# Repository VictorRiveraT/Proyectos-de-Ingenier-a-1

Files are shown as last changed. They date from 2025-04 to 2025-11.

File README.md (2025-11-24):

<p align="left">
  
  <h1 align="center">SafeFry: Kit Portable para la Evaluación de Aceite Vegetal</h1>
</p>

## Descripción General
### Proyecto: Sistema de Monitoreo de Calidad de Aceite de Cocina Reutilizado mediante capacitancia y turbidez

SafeFry se centra en el desarrollo de un dispositivo portátil y de bajo costo que combina:

- La medición de la **capacitancia** del aceite de cocina reutilizado, como indicador de cambio en sus propiedades dieléctricas asociadas al deterioro.
- El sondeo de la **turbidez**, para estimar la presencia de impurezas y particulas asociadas al deterior del aceite.

La iniciativa busca facilitar la fiscalización técnica en entornos gastronómicos informales y brindar herramientas accesibles y confiables para la inspección sanitaria. De esta forma, se contribuye a la reducción de riesgos asociados al consumo de aceites degradados y a la prevención de enfermedades.

### ODS 3: Salud y Bienestar

El proyecto se enmarca dentro del ODS 3: Salud y Bienestar, particularmente en la meta 3.9: “Reducir sustancialmente el número de muertes y enfermedades por productos químicos peligrosos y contaminación del aire, agua y suelo” (ONU, 2023).

Este dispositivo busca:
- Contribuir a la seguridad alimentaria en contextos urbanos y rurales.
- Apoyar a instituciones y actores locales en la inspección sanitaria.
- Reducir el riesgo para la salud humana derivado del consumo de aceites en mal estado.

## Características Principales

- **Medición eléctrica:** Integración de un sensor capacitivo para análisis indirecto de la constante dieéectrica en el aceite, relacionado con su grado de deterioro.
- **Medición optica:** Uso de un sensor de turbidez como parametro indirecto del deterioro, con criterio de alerta en niveles altos de particulas e impurezas.
- **Interfaz intuitiva:** Visualización clara de resultados (capacitancia, turbidez, diagnóstico final).
- **Diseño portátil:** Prototipo compacto, accesible y replicable en diferentes contextos.

## Motivación y Contexto

El acceso a herramientas accesibles y confiables para evaluar la calidad de aceites de cocina reutilizados suele estar limitado por altos costos, falta de precisión o la necesidad de equipos especializados. Esto genera un riesgo para la salud pública, especialmente en entornos gastronómicos informales donde los controles sanitarios son reducidos. </p>
SafeFry nace con la intención de democratizar la evaluación de aceites, ofreciendo una alternativa portátil, de bajo costo y sencilla de implementar, que combina la medición de capacitancia con el análisis de turbidez. </p>
Este proyecto también responde a la necesidad académica de brindar a los estudiantes experiencias prácticas en el uso de tecnologías emergentes (sensado químico y sensado optico), facilitando la comprensión de conceptos de seguridad alimentaria, control de calidad y sostenibilidad en escenarios reales.

## Funcionamiento Esperado

1. La muestras de aceite se preparan y colocan en compartimentos de medición.
2. El sensor capacitivo mide la **capacitancia aparente** de la muestra, relacionada con cambios en su composición.
3. El sensor optico mide la **turbidez** del aceite para detectar su grado de deterioro.
4. El sistema procesa ambos valores y los compara con parámetros de referencia.
5. Se muestra el resultado en pantalla: Apto / No apto.

## Resultados Esperados

- Medición confiable de **capacitancia** y **turbidez** como parámetros de referencia para la evaluación de la calidad del aceite.
- Prototipo portátil y de bajo costo, diseñado para ser implementado en entornos gastronómicos informales y educativos.
- Contribución académica y social, fortaleciendo la seguridad alimentaria y promoviendo el uso de tecnologías accesibles para el control de calidad.

## Estructura del Proyecto

A continuación se detalla la organización de carpetas y archivos del repositorio:

```text
Proyectos-de-Ingenier-a-1/                        # Repositorio raíz
│
├── README.md                                     # Presentación general y documentación global
├── Fundamentos de Diseño/                        # Carpeta del curso predecesor
│
└── Proyectos de Ingeniería/                      # Carpeta principal del curso actual
    ├── Certificados/                             # Documentos de gestión y madurez TRL
    ├── Imágenes/                                 # Recursos visuales subidos
    ├── Sobre Nosotros/                           # Información de los integrantes
    ├── Talleres/                                 # Talleres y laboratorios del curso
    │
    └── Documentación/                            # Documentación técnica de ingeniería
        ├── 1.Justificación_Científica.md         # Base científica del proyecto
        ├── 2.Lista_de_Requerimientos.md          # Requisitos de portabilidad y técnicos
        ├── 3.Caja_Negra_y_Esquema_Funciones.md   # Diagramas funcionales del sistema
        ├── 4.Matriz_Morfológica.md               # Evaluación de alternativas de diseño
        ├── 5.Tabla_de_Valoración.md              # Selección de la solución final
        ├── 6.Bocetos.md                          # Dibujos preliminares del prototipo
        ├── 7.Modelo_3D.md                        # Modelado del prototipo en Onshape
        ├── 8.Esquemático.md                      # Diagramas de conexiones electrónicas
        │
        └── 9. Código/                            # Sección de Software y Firmware
            ├── README.md                         # Presentación de "SafeFry Pro" (IoT)
            │
            ├── Código_Node_Red/                  # Lógica del Dashboard IoT
            │   ├── Node-Red_Flow-Safefry.json    # Flujo completo: Dashboard y Gráficas
            │   └── README.md                     # Presentación del Flujo Node-RED
            │
            └── Código_Safefry_Aceite/            # Proyecto de Firmware (PlatformIO)
                ├── .gitignore                    # Archivos ignorados por Git
                ├── platformio.ini                # Configuración del entorno y librerías
                │
                ├── .vscode/                      # Configuración del editor VSCode
                │   └── extensions.json           # Extensiones recomendadas
                │
                ├── include/                      # Archivos de cabecera (.h) globales
                │   └── README                    # Info sobre headers
                │
                ├── lib/                          # Librerías privadas específicas
                │   └── README                    # Info sobre librerías estáticas
                │
                ├── test/                         # Pruebas unitarias del código
                │   └── README                    # Info sobre PlatformIO Test Runner
                │
                └── src/                          # Código fuente principal (C++)
                    ├── main.cpp                  # Archivo principal (Lógica de control)
                    ├── lcd_display.cpp           # Código control pantalla LCD
                    ├── lcd_display.h             # Definiciones pantalla LCD
                    ├── pulsador.cpp              # Lógica de los botones físicos
                    ├── pulsador.h                # Definiciones de botones
                    ├── sensor_capacitancia.cpp   # Lectura del sensor capacitivo (Aceite)
                    ├── sensor_capacitancia.h     # Definiciones sensor capacitivo
                    ├── sensores_turbidez.cpp     # Lectura de turbidez
                    └── sensores_turbidez.h       # Definiciones turbidez
```

## Integrantes:

| Miembro | Rol | Función Principal | Correo |
| :---: | :---: | :---: | :---: |
| **Rivera Torres Victor Daniel** | Diseño mecánico y prototipo | Diseñar y generar planos; iterar el prototipo físico | victor.rivera@upch.pe |
| **Morales Alvarado Jesús Anselmo** | Firmware y Telemetría | Programar filtrado y lógica; telemetría con envío al sitio web | jesus.morales@upch.pe |
| **Rioja Cruz Vanesa Doris** | Investigación y Requisitos | Liderar la revisión bibliográfica, definir métricas/umbrales y protocolos de calibración | vanesa.rioja@upch.pe |
| **Oscco Pizarro Gisela** | Gestión de Repositorio y Flujo de Desarrollo | Estructurar y mantener el GitHub, control de versiones de datos | gisela.oscco@upch.pe |
| **Huamani Salazar Jander** | Electrónica y Ensamble | Diseñar el esquema, cableado y ensamble electrónico | jander.huamani@upch.pe |

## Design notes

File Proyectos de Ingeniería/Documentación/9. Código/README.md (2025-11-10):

# SafeFry Pro - Sistema de Monitoreo de Calidad de Aceite

Sistema IoT profesional para monitoreo en tiempo real de la calidad del aceite de fritura mediante sensores capacitivos y de turbidez, con dashboard web interactivo y control remoto vía WiFi/UDP.

---

## Tabla de Contenidos

- [Características](#-características)
- [Requisitos](#-requisitos-del-sistema)
- [Instalación](#-instalación)
- [Documentación de Código](#-documentación-de-código)
- [Configuración](#-configuración)
- [Uso del Sistema](#-uso-del-sistema)
- [Dashboard Node-RED](#-dashboard-node-red)
- [API y Protocolos](#-api-y-protocolos)
- [Calibración de Sensores](#-calibración-de-sensores)
- [Solución de Problemas](#-solución-de-problemas)

---

## Características

### Funcionalidades Principales

-  **Monitoreo Multi-Sensor**: Medición simultánea de capacitancia y turbidez
-  **Conectividad WiFi**: Transmisión de datos en tiempo real
-  **Dashboard Web**: Interfaz gráfica profesional con Node-RED
-  **Control Remoto**: Pausa/reanuda mediciones desde cualquier dispositivo
-  **Display LCD**: Visualización local de datos y estado del sistema
-  **Toma de Decisiones**: Clasificación automática del aceite (Apto/No Apto)
-  **Histórico de Datos**: Gráficas temporales de evolución
-  **Sistema Modular**: Código organizado en clases reutilizables
-  **Calibración Flexible**: Ajuste de umbrales según tipo de aceite

### Sensores Implementados

| Sensor | Tipo | GPIO | Protocolo | Función |
|---|---|---|---|---|
| **Capacitivo** | Analógico | 25 | ADC 12-bit | Mide degradación molecular |
| **Turbidez 1** | Digital | 16/17 | UART (9600) | Detecta partículas suspendidas |
| **Turbidez 2** | Digital | 27/14 | UART (9600) | Redundancia y promediado |

### Interfaces de Usuario

1. **LCD 16x2 I2C**: Display físico local (tiempo real)
2. **Dashboard Web**: Interfaz gráfica accesible desde navegador
3. **Monitor Serial**: Logs detallados para debugging (115200 baudios)

---

## Requisitos del Sistema

### Hardware Necesario

#### Componentes Principales
- **Microcontrolador**: ESP32 DevKit (240MHz, 320KB RAM, WiFi integrado)
- **Display**: LCD 16x2 con módulo I2C (dirección 0x27)
- **Sensores**:
  - 1x Sensor capacitivo analógico (0-4095 ADC)
  - 2x Sensores de turbidez UART (protocolo propietario)
- **Entrada**: Pulsador momentáneo (pull-down)
- **Alimentación**: 5V/2A mínimo

### Software Necesario

#### En el ESP32
- **PlatformIO IDE**: v6.0 o superior (extensión VSCode)
- **Framework**: Arduino para ESP32 v3.x
- **Librerías**:
  - `ArduinoJson` v7.4.2+ (manejo de JSON)
  - `LiquidCrystal_I2C` v1.1.4+ (control LCD)
  - `WiFi` (integrado ESP32)
  - `WiFiUdp` (integrado ESP32)

#### En el Servidor (PC)
- **Node.js**: v14 LTS o superior
- **Node-RED**: v3.x
- **node-red-dashboard**: v3.6.6+

---

## Instalación

### 1. Configurar PlatformIO

```bash
# Instalar PlatformIO Core (si no está instalado)
pip install platformio

# O instalar la extensión en VSCode
# Buscar: "PlatformIO IDE" en el marketplace
```

### 2. Instalar Dependencias del ESP32

```bash
# Las dependencias se instalan automáticamente desde platformio.ini
pio pkg install

# Verificar instalación
pio pkg list
```

**Salida esperada:**
```
Library Manager
===============
ArduinoJson @ 7.4.2
LiquidCrystal_I2C @ 1.1.4
```

### 3. Configurar Node-RED

```bash
# Instalar Node-RED globalmente
npm install -g --unsafe-perm node-red

# Instalar Dashboard
npm install -g node-red-dashboard

# Iniciar Node-RED
node-red
```

### 4. Importar el Flow de Node-RED

1. Abrir navegador: `http://localhost:1880`
2. Menú ☰ → **Import** → **Clipboard**
3. Pegar el contenido de `nodered-flow.json`
4. Click **Import**
5. Click **Deploy** (botón rojo)

### 5. Configurar WiFi en el Código

Editar `src/main.cpp` (líneas 12-13):

```cpp
const char* WIFI_SSID = "TU_RED_WIFI";        // ← Cambiar
const char* WIFI_PASSWORD = "TU_CONTRASEÑA";  // ← Cambiar
```

Editar dirección IP del servidor (línea 17):

```cpp
const char* UDP_SERVER_IP = "192.168.1.XXX";  // ← IP de tu PC
```

### 6. Compilar y Subir al ESP32

```bash
# Compilar
pio run

# Subir al ESP32 (automáticamente detecta puerto)
pio run -t upload

# Abrir monitor serial
pio device monitor
```
---

## Documentación de Código

### `main.cpp` - Programa Principal

**Ubicación:** `src/main.cpp`

**Responsabilidades:**
- Orquestación de todo el sistema
- Conexión WiFi y gestión de red
- Comunicación UDP bidireccional
- Loop principal de medición
- Manejo de interrupciones del botón

**Estructura:**

```cpp
// ========== INCLUDES Y CONFIGURACIÓN ==========
#include <Arduino.h>
#include <WiFi.h>
#include <WiFiUdp.h>
#include <ArduinoJson.h>
#include "sensor_capacitancia.h"
#include "sensores_turbidez.h"
#include "lcd_display.h"
#include "pulsador.h"

// ========== CONFIGURACIÓN WiFi/UDP ==========
const char* WIFI_SSID = "...";
const char* WIFI_PASSWORD = "...";
const char* UDP_SERVER_IP = "...";
const int UDP_SERVER_PORT = 1880;
const int UDP_LOCAL_PORT = 1881;

// ========== INSTANCIAS DE OBJETOS ==========
LCDDisplay lcd(0x27, 21, 22);
SensorCapacitancia sensorCapacitivo(25);
// ... (otros sensores)

// ========== UMBRALES DE DECISIÓN ==========
const float UMBRAL_CAPACITIVO = 50.0;   // 50% degradación
const float UMBRAL_TURBIDEZ = 40.0;     // 40% turbidez

// ========== ESTRUCTURA DE DATOS ==========
struct DatosSensores {
    int capacitivoRaw;
    float capacitivoPorcentaje;
    String capacitivoEstado;
    bool capacitivoApto;
    
    int turbidez1Raw;
    int turbidez2Raw;
    float turbidezPromedio;
    String turbidezEstado;
    bool turbidezApto;
    
    bool sistemaApto;
    String decisionFinal;
};
```

**Funciones Principales:**

#### `void conectarWiFi()`
```cpp
// Conecta el ESP32 a la red WiFi configurada
// Muestra progreso en LCD y Serial
// Timeout: 30 intentos (15 segundos)
// Retorna: void (actualiza estado global)
```

#### `void enviarDatosUDP()`
```cpp
// Envía datos de sensores al servidor Node-RED
// Formato: JSON con 13 campos
// Protocolo: UDP unicast al puerto 1880
// Frecuencia: Según intervaloMedicion (default 5s)
```

#### `void procesarComandosUDP()`
```cpp
// Escucha comandos desde Node-RED en puerto 1881
// Comandos soportados:
//   - {"comando":"pausar"}
//   - {"comando":"reanudar"}
//   - {"comando":"intervalo", "valor":5000}
```

#### `void leerSensores()`
```cpp
// Lee todos los sensores y procesa datos
// 1. Lee sensor capacitivo (50 muestras promediadas)
// 2. Lee ambos sensores de turbidez (10 muestras c/u)
// 3. Calcula promedios y porcentajes
// 4. Determina estados (EXCELENTE/BUENO/REGULAR/MALO)
// 5. Toma decisión final (APTO/NO APTO)
```

**Loop Principal:**

```cpp
void loop() {
    // 1. Verificar WiFi cada 30 segundos
    verificarWiFi();
    
    // 2. Procesar comandos UDP entrantes
    procesarComandosUDP();
    
    // 3. Verificar botón físico (interrupción)
    if (boton.presionado()) {
        sistemaPausado = !sistemaPausado;
    }
    
    // 4. Ejecutar mediciones si está activo
    if (!sistemaPausado) {
        if (millis() - ultimaMedicion >= intervaloMedicion) {
            leerSensores();
            enviarDatosUDP();
            lcd.mostrarResultados(...);
            ultimaMedicion = millis();
        }
    }
}
```

---

###  `lcd_display.h/.cpp` - Control del Display LCD

**Ubicación:** `src/lcd_display.h` + `src/lcd_display.cpp`

**Descripción:**
Clase para manejar un LCD 16x2 con módulo I2C. Proporciona métodos para mostrar diferentes pantallas del sistema.

**Interfaz Pública:**

```cpp
class LCDDisplay {
public:
    LCDDisplay(uint8_t addr, int sda, int scl);
    
    // Configuración
    void begin();
    bool detectar();
    
    // Pantallas del sistema
    void mostrarInicio();
    void mostrarEsperandoBoton();
    void mostrarIniciandoSistema();
    void mostrarLeyendoSensores();
    void mostrarResultados(int capRaw, float capPorc, 
                          int turbRaw, float turbPorc, 
                          bool apto);
    void mostrarPausado();
    void mostrarError(String mensaje);
    
    // Pantallas WiFi
    void mostrarConectandoWiFi();
    void mostrarWiFiConectado(String ip);
    
    // Control básico
    void limpiar();
    void backlight(bool encender);
};
```

**Ejemplo de Uso:**

```cpp
LCDDisplay lcd(0x27, 21, 22);  // Dirección I2C, SDA, SCL

void setup() {
    lcd.begin();
    
    if (lcd.detectar()) {
        lcd.mostrarInicio();
    } else {
        lcd.mostrarError("LCD no detect");
    }
}
```

**Pantallas Implementadas:**

| Pantalla | Duración | Uso |
|---|---|-----|
| `mostrarInicio()` | 2s | Splash screen inicial |
| `mostrarConectandoWiFi()` | Variable | Durante conexión WiFi |
| `mostrarWiFiConectado(ip)` | 2s | Confirmación de conexión |
| `mostrarEsperandoBoton()` | Permanente | Espera inicio del usuario |
| `mostrarLeyendoSensores()` | 1s | Durante lectura |
| `mostrarResultados(...)` | 5s | Datos + decisión (alternante) |
| `mostrarPausado()` | Permanente | Sistema en pausa |

---

### `sensor_capacitancia.h/.cpp` - Sensor Capacitivo

**Ubicación:** `src/sensor_capacitancia.h` + `src/sensor_capacitancia.cpp`

**Descripción:**
Clase para leer y procesar un sensor capacitivo analógico que mide la degradación del aceite basándose en cambios en su constante dieléctrica.

**Principio de Funcionamiento:**
```
Aceite Fresco    →  Alta capacitancia (≈3130)  →  0% degradación
Aceite Degradado →  Baja capacitancia (≈3140)  →  100% degradación
```

**Interfaz Pública:**

```cpp
class SensorCapacitancia {
public:
    SensorCapacitancia(int pinSensor);
    
    // Configuración
    void begin();
    void calibrar(int aire, int agua, int limpio, int sucio);
    void setNumLecturas(int num);
    
    // Lectura
    int leerRaw();              // Valor ADC (0-4095)
    float leerPorcentaje();     // Degradación (0-100%)
    
    // Utilidades
    String obtenerEstado();
    String obtenerEstadoDetallado(float porcentaje);
};
```

**Calibración:**

```cpp
sensorCapacitivo.calibrar(
    3430,  // Valor en aire (máximo)
    290,   // Valor en agua (mínimo)
    3130,  // Aceite limpio
    3140   // Aceite degradado
);
```

**Algoritmo de Lectura:**

```cpp
int SensorCapacitancia::leerRaw() {
    long suma = 0;
    for (int i = 0; i < numLecturas; i++) {  // Default: 50
        suma += analogRead(pin);
        delay(10);  // 10ms entre muestras
    }
    return suma / numLecturas;  // Promedio
}

float SensorCapacitancia::leerPorcentaje() {
    int raw = leerRaw();
    // Mapeo inverso: limpio(3130)→0%, sucio(3140)→100%
    return map(raw, valorSucio, valorLimpio, 0, 100);
}
```

**Estados de Clasificación:**

| Porcentaje | Estado | Descripción |
|---|---|---|
| 0-24% | EXCELENTE | Aceite en condiciones óptimas |
| 25-49% | BUENO | Aceite apto, sin degradación significativa |
| 50-74% | REGULAR | Aceite con degradación moderada |
| 75-100% | MALO | Aceite altamente degradado, cambiar |

---

### `sensores_turbidez.h/.cpp` - Sensores de Turbidez

**Ubicación:** `src/sensores_turbidez.h` + `src/sensores_turbidez.cpp`

**Descripción:**
Clase para comunicarse con sensores de turbidez que usan protocolo UART propietario. Mide la cantidad de partículas suspendidas en el aceite.

**Protocolo de Comunicación:**

```
Comando de lectura (5 bytes):
[0x18] [0x05] [0x00] [0x01] [0x0D]
  ↓      ↓      ↓      ↓      ↓
 Start  Cmd   Addr  Length  End

Respuesta del sensor (5 bytes):
[0x??] [0x??] [0x??] [VALUE] [0x??]
                       ↑
                 Dato de turbidez (0-255)
```

**Interfaz Pública:**

```cpp
class SensorTurbidez {
public:
    SensorTurbidez(HardwareSerial* port, int rx, int tx);
    
    // Configuración
    void begin();
    void calibrar(int limpio, int sucio);
    void setNumLecturas(int num);
    
    // Lectura
    int leerRaw();                      // Valor (0-255)
    float leerPorcentajeSuciedad();    // Suciedad (0-100%)
    
    // Utilidades
    String obtenerEstado();
    String obtenerEstadoDetallado(float porcentaje);
    bool disponible();
};
```

**Calibración:**

```cpp
sensorTurbidez1.calibrar(
    243,  // Aceite limpio (valor alto)
    205   // Aceite sucio (valor bajo)
);
```

**Algoritmo de Lectura:**

```cpp
int SensorTurbidez::leerRaw() {
    long suma = 0;
    int lecturasValidas = 0;
    
    for (int i = 0; i < 10; i++) {  // 10 intentos
        // 1. Limpiar buffer
        while (serial->available()) serial->read();
        
        // 2. Enviar comando
        serial->write(comandoLectura, 5);
        
        // 3. Esperar respuesta (timeout 500ms)
        unsigned long inicio = millis();
        while (serial->available() < 5 && 
               (millis() - inicio) < 500) {
            delay(10);
        }
        
        // 4. Leer respuesta
        if (serial->available() >= 5) {
            for (int j = 0; j < 5; j++) {
                buffer[j] = serial->read();
            }
            suma += buffer[3];  // Byte de datos
            lecturasValidas++;
        }
        
        delay(100);  // Pausa entre lecturas
    }
    
    return (lecturasValidas > 0) ? 
           suma / lecturasValidas : -1;  // -1 = error
}
```

**Promediado de Sensores:**

```cpp
// En main.cpp
float turbidez1 = sensorTurbidez1.leerPorcentajeSuciedad();
float turbidez2 = sensorTurbidez2.leerPorcentajeSuciedad();

if (turbidez1 >= 0 && turbidez2 >= 0) {
    turbidezPromedio = (turbidez1 + turbidez2) / 2.0;  // Promedio
} else if (turbidez1 >= 0) {
    turbidezPromedio = turbidez1;  // Solo sensor 1
} else if (turbidez2 >= 0) {
    turbidezPromedio = turbidez2;  // Solo sensor 2
} else {
    turbidezPromedio = -1;  // Error total
}
```

---

### `pulsador.h/.cpp` - Control del Botón

**Ubicación:** `src/pulsador.h` + `src/pulsador.cpp`

**Descripción:**
Clase para manejar un pulsador con interrupciones y antirrebote por software.

**Interfaz Pública:**

```cpp
class Pulsador {
public:
    Pulsador(int pinBoton, unsigned long debounce = 200);
    void begin();
    bool presionado();  // Retorna true si fue presionado
    
private:
    static void IRAM_ATTR manejarInterrupcion();
    static volatile bool flagGlobal;
    static volatile unsigned long ultimoTiempoGlobal;
};
```

**Implementación del Antirrebote:**

```cpp
void IRAM_ATTR Pulsador::manejarInterrupcion() {
    unsigned long tiempoActual = millis();
    
    // Ignorar rebotes en 200ms
    if (tiempoActual - ultimoTiempoGlobal > 200) {
        flagGlobal = true;
        ultimoTiempoGlobal = tiempoActual;
    }
}

bool Pulsador::presionado() {
    if (flagGlobal) {
        flagGlobal = false;  // Reset flag
        return true;
    }
    return false;
}
```

**Configuración de Hardware:**

```
GPIO 26 ────┬──── Pulsador ──── VCC
            │
           ═╧═  10kΩ Pull-down
            │
           GND
```

---

## Configuración

### Configuración WiFi

Editar en `src/main.cpp`:

```cpp
// ========== CONFIGURACIÓN WiFi ==========
const char* WIFI_SSID = "TU_RED_WIFI";
const char* WIFI_PASSWORD = "TU_CONTRASEÑA";
```

**Requisitos:**
-  Red WiFi 2.4 GHz (ESP32 no soporta 5 GHz)
-  DHCP habilitado (asignación automática de IP)
-  Sin firewall que bloquee UDP

### Configuración UDP

```cpp
// ========== CONFIGURACIÓN UDP ==========
const char* UDP_SERVER_IP = "192.168.1.100";  // IP de tu PC
const int UDP_SERVER_PORT = 1880;             // Puerto entrada
const int UDP_LOCAL_PORT = 1881;              // Puerto escucha
```

**Verificar IP de tu PC:**

Windows:
```cmd
ipconfig
```

Linux/Mac:
```bash
ifconfig
```

### Configuración de Umbrales

```cpp
// ========== UMBRALES DE DECISIÓN ==========
const float UMBRAL_CAPACITIVO = 50.0;  // % degradación
const float UMBRAL_TURBIDEZ = 40.0;    // % turbidez
```

**Lógica de Decisión:**
```cpp
bool aptoCap = (capacitancia < UMBRAL_CAPACITIVO);
bool aptoTurb = (turbidez < UMBRAL_TURBIDEZ);
bool sistemaApto = aptoCap && aptoTurb;  // Ambos deben ser aptos
```

### Configuración de Sensores

#### Sensor Capacitivo
```cpp
sensorCapacitivo.begin();
sensorCapacitivo.calibrar(3430, 290, 3130, 3140);
sensorCapacitivo.setNumLecturas(50);  // 50 muestras
```

#### Sensores de Turbidez
```cpp
sensorTurbidez1.begin();
sensorTurbidez1.calibrar(243, 205);  // Limpio, Sucio

sensorTurbidez2.begin();
sensorTurbidez2.calibrar(243, 205);
```

---

## Uso del Sistema

### Inicio del Sistema

1. **Conexión de Hardware**
   - Conectar todos los sensores según diagrama
   - Conectar LCD I2C
   - Conectar pulsador
   - Alimentar ESP32 (5V/2A)

2. **Arranque Automático**
   ```
   [LCD] SAFEFRY v1.1
         Monitor Aceite
   
   [LCD] Conectando
         WiFi...
   
   [LCD] WiFi OK!
         192.168.1.123
   
   [LCD] Presiona boton
         para iniciar
   ```

3. **Iniciar Mediciones**
   - Presionar botón físico (GPIO 26)
   - O desde dashboard web: click **▶️ REANUDAR**

### Operación Normal

**Ciclo de Medición (cada 5 segundos):**

```
1. [LCD] Leyendo sensores...         (1 segundo)
2. [Serial] Log detallado de datos   (contínuo)
3. [LCD] C:3135  T:223               (3 segundos)
        45%    35%    OK
4. [LCD] DECISION FINAL:             (2 segundos)
        *** APTO ***
5. [UDP] Envío de JSON al servidor
6. [Dashboard] Actualización gráfica
```

### Control Remoto

Desde el dashboard web (`http://IP_PC:1880/ui`):

| Acción | Efecto | Feedback |
|---|---|---|
| **⏸️ PAUSAR** | Detiene mediciones | LCD: "SISTEMA PAUSADO" |
| **▶️ REANUDAR** | Inicia mediciones | LCD: "Iniciando... Sistema" |
| ** Slider** | Cambia intervalo (1-30s) | Serial: "Intervalo cambiado a: Xs" |

### Lectura del LCD

**Pantalla 1 - Valores RAW (3s):**
```
┌────────────────┐
│C:3135    T:223 │  ← Valores RAW de sensores
│45%       35% OK│  ← Porcentajes + Estado
└────────────────┘
```

**Pantalla 2 - Decisión (2s):**
```
┌────────────────┐
│DECISION FINAL: │
│  *** APTO ***  │
└────────────────┘
```

### Monitor Serial

**Ejemplo de salida:**

```
╔════════════════════════════════════════════╗
║         LEYENDO SENSORES SAFEFRY          ║
╚════════════════════════════════════════════╝

 SENSOR CAPACITIVO:
  RAW: 3135 | Degradación: 45.5% | Estado: BUENO | ✅ APTO

 SENSORES DE TURBIDEZ:
  Sensor 1: 225 (35.2%)
  Sensor 2: 220 (34.8%)
  Promedio: 35.0% NTU | Estado: BUENO | ✅ APTO

╔════════════════════════════════════════════╗
║        DECISIÓN FINAL: ✅ APTO            ║
╚════════════════════════════════════════════╝

 Datos enviados por UDP:
{"timestamp":12345,"capacitancia_raw":3135,...}
```

---

## Dashboard Node-RED

### Acceso al Dashboard

```
Local:     http://localhost:1880/ui
Red local: http://192.168.1.100:1880/ui
Móvil:     http://IP_PC:1880/ui
```

### Componentes del Dashboard

#### 1. Indicadores Principales

**Gauges Tipo Donut:**
- **Turbidez**: 0-100% (Verde: 0-40, Amarillo: 40-70, Rojo: 70-100)
- **Capacitancia**: 0-100% (Verde: 0-50, Amarillo: 50-75, Rojo: 75-100)

**Características:**
- Actualización en tiempo real
- Animación suave
- Colores dinámicos según valor

#### 2. Estado del Sistema

**Banner Principal:**
```css
┌────────────────────────────────────┐
│                                    │
│         ✅ APTO                    │  ← Gradiente morado
│                                    │     Fuente grande, sombras
└────────────────────────────────────┘
```

**Indicador de Decisión:**
- ✅ SISTEMA APTO (verde)
- ❌ NO APTO (rojo)

#### 3. Histórico de Mediciones

**Gráfica de Líneas:**
- Eje X: Tiempo (HH:mm:ss)
- Eje Y: Porcentaje (0-100%)
- Línea azul: Turbidez
- Línea naranja: Capacitancia
- Histórico: Últimos 5 minutos
- Interpolación: Lineal
- Zoom: Interactivo

#### 4. Valores RAW

**Displays grandes:**
```
┌─────────────────────┐  ┌─────────────────────┐
│    Turbidez RAW     │  │    Capacitancia RAW │
│                     │  │                     │
│       223           │  │       3135          │
│   (fuente 36px)     │  │   (fuente 36px)     │
└─────────────────────┘  └─────────────────────┘
```

#### 5. Estados Detallados

**Texto descriptivo:**
-  Capacitancia: BUENO (45.5%)
-  Turbidez: EXCELENTE (35.0%)

**Indicadores de estado:**
- Cap: ✅ APTO / ❌ NO APTO
- Turb: ✅ APTO / ❌ NO APTO
- Sistema: ▶️ ACTIVO / ⏸️ PAUSADO

#### 6. Resumen Completo

**Tabla HTML estilizada:**

| Parámetro | Valor | Estado |
|---|---|---|
| Capacitancia RAW | 3135 | ✅ APTO |
| Capacitancia % | 45.5% | BUENO |
| Turbidez Sensor 1 RAW | 225 | - |
| Turbidez Sensor 2 RAW | 220 | - |
| Turbidez Promedio RAW | 223 | ✅ APTO |
| Turbidez % | 35.0% | EXCELENTE |
| **DECISIÓN FINAL** | **✅ APTO** | **✅ SISTEMA APTO** |
| Última actualización | 09/11/2025 15:30:45 | - |

**Características:**
- Hover effects
- Badges coloridos
- Responsive design
- Exportable

#### 7. Control Remoto

**Botones:**
- ⏸️ **PAUSAR**: Botón rojo, detiene mediciones
- ▶️ **REANUDAR**: Botón verde, inicia mediciones

**Slider de Intervalo:**
- Rango: 1-30 segundos
- Paso: 1 segundo
- Feedback inmediato
- Indicador de valor actual

### Ejemplo Visual del Dashboard

```
╔═══════════════════════════════════════════════════════════╗
║                SafeFry Dashboard Pro                    ║
╠═══════════════════════════════════════════════════════════╣
║    INDICADORES PRINCIPALES                              ║
║  ┌──────────┐  ┌──────────┐                             ║
║  │    35%  │  │    45%  │  (Gauges donut)             ║
║  └──────────┘  └──────────┘                             ║
║                                                          ║
║  🚦 ESTADO DEL SISTEMA                                   ║
║  ┌────────────────────────────────────────┐             ║
║  │          ✅ APTO                       │ (Banner)    ║
║  └────────────────────────────────────────┘             ║
║  ✅ SISTEMA APTO                           (Decisión)    ║
║                                                          ║
║  📈 HISTÓRICO                                            ║
║  ┌────────────────────────────────────────┐             ║
║  │      ╱╲    ╱╲                          │             ║
║  │    ╱    ╲╱    ╲                        │ (Gráfica)   ║
║  │  ╱                                     │             ║
║  └────────────────────────────────────────┘             ║
║                                                          ║
║  🔢 VALORES RAW                                          ║
║  ┌──────────┐  ┌──────────┐                             ║
║  │   223    │  │   3135   │                             ║
║  └──────────┘  └──────────┘                             ║
║                                                          ║
║    ESTADOS: ✅ Cap OK  ✅ Turb OK  ▶️ Activo            ║
║                                                          ║
║    TABLA COMPLETA                                       ║
║  [Tabla con todos los datos detallados]                 ║
║                                                          ║
║    CONTROL REMOTO                                      ║
║  [⏸️ PAUSAR] [▶️ REANUDAR] [━━━━◉━━━ 5s]               ║
╚═══════════════════════════════════════════════════════════╝
```

---

## 📡 API y Protocolos

### Protocolo UDP

#### Formato de Datos (ESP32 → Node-RED)

**Puerto:** 1880  
**Protocolo:** UDP  
**Formato:** JSON  

**Estructura del JSON:**

```json
{
  "timestamp": 12345,
  "capacitancia_raw": 3135,
  "capacitancia": 45.5,
  "capacitancia_estado": "BUENO",
  "capacitancia_apto": true,
  "turbidez1_raw": 225,
  "turbidez2_raw": 220,
  "turbidez_promedio_raw": 223,
  "turbidez": 35.0,
  "turbidez_estado": "EXCELENTE",
  "turbidez_apto": true,
  "sistema_apto": true,
  "estado": "✅ APTO",
  "pausado": false
}
```

**Campos:**

| Campo | Tipo | Rango | Descripción |
|---|---|---|---|
| `timestamp` | int | 0-∞ | Milisegundos desde inicio |
| `capacitancia_raw` | int | 0-4095 | Valor ADC 12-bit |
| `capacitancia` | float | 0-100 | % de degradación |
| `capacitancia_estado` | string | - | EXCELENTE/BUENO/REGULAR/MALO |
| `capacitancia_apto` | bool | - | true/false |
| `turbidez1_raw` | int | 0-255 | Sensor 1 RAW |
| `turbidez2_raw` | int | 0-255 | Sensor 2 RAW |
| `turbidez_promedio_raw` | int | 0-255 | Promedio RAW |
| `turbidez` | float | 0-100 | % de suciedad |
| `turbidez_estado` | string | - | EXCELENTE/BUENO/REGULAR/MALO/MUY_MALO |
| `turbidez_apto` | bool | - | true/false |
| `sistema_apto` | bool | - | true/false (AND de ambos) |
| `estado` | string | - | "✅ APTO" / "❌ NO APTO" |
| `pausado` | bool | - | Estado del sistema |

#### Comandos (Node-RED → ESP32)

**Puerto:** 1881  
**Protocolo:** UDP Broadcast  
**Formato:** JSON  

**1. Pausar Sistema:**
```json
{
  "comando": "pausar"
}
```

**2. Reanudar Sistema:**
```json
{
  "comando": "reanudar"
}
```

**3. Cambiar Intervalo:**
```json
{
  "comando": "intervalo",
  "valor": 5000
}
```
**Rango válido:** 1000-60000 ms

### Diagrama de Secuencia

```
ESP32                    Node-RED
  │                         │
  ├─────── WiFi Connect ────│
  │◄──────── DHCP IP ───────┤
  │                         │
  ├── UDP(1880): JSON ──────►│ [Procesar datos]
  │                         │ [Actualizar dashboard]
  │                         │ [Usuario: Click PAUSAR]
  │◄─ UDP(1881): {"pausar"} ┤
  │                         │
  [Sistema pausado]         │
  │                         │
  │◄─ UDP(1881): {"reanudar"} ┤
  │                         │
  ├── UDP(1880): JSON ──────►│
  │    (ciclo continúa)      │
```

---

## Calibración de Sensores

### Sensor Capacitivo

#### Procedimiento de Calibración

**1. Calibración en Aire (máximo):**
```cpp
// Sensor al aire libre, sin contacto
int valorAire = sensorCapacitivo.leerRaw();
// Valor esperado: ~3430
```

**2. Calibración en Agua (mínimo):**
```cpp
// Sensor sumergido en agua destilada
int valorAgua = sensorCapacitivo.leerRaw();
// Valor esperado: ~290
```

**3. Calibración con Aceite Limpio:**
```cpp
// Sensor en aceite fresco sin usar
int valorLimpio = sensorCapacitivo.leerRaw();
// Valor esperado: ~3130
```

**4. Calibración con Aceite Degradado:**
```cpp
// Sensor en aceite muy usado/oscuro
int valorSucio = sensorCapacitivo.leerRaw();
// Valor esperado: ~3140
```

**5. Aplicar Calibración:**
```cpp
sensorCapacitivo.calibrar(
    valorAire,    // 3430
    valorAgua,    // 290
    valorLimpio,  // 3130
    valorSucio    // 3140
);
```

#### Troubleshooting

| Problema | Causa | Solución |
|---|---|---|
| Lecturas erráticas | Ruido eléctrico | Agregar capacitor 100nF |
| Valores fuera de rango | Mala conexión | Verificar soldaduras |
| No detecta cambios | Sensor dañado | Reemplazar sensor |

### Sensores de Turbidez

#### Procedimiento de Calibración

**1. Calibración con Aceite Limpio:**
```cpp
// Sumergir sensor en aceite fresco
// Realizar múltiples lecturas
int sum = 0;
for (int i = 0; i < 10; i++) {
    sum += sensorTurbidez1.leerRaw();
    delay(1000);
}
int valorLimpio = sum / 10;
// Valor esperado: ~243
```

**2. Calibración con Aceite Sucio:**
```cpp
// Aceite muy usado o con partículas añadidas
int valorSucio = /* promedio de 10 lecturas */;
// Valor esperado: ~205
```

**3. Aplicar Calibración:**
```cpp
sensorTurbidez1.calibrar(valorLimpio, valorSucio);
sensorTurbidez2.calibrar(valorLimpio, valorSucio);
```

#### Mantenimiento

- **Limpieza:** Limpiar lentes cada semana con alcohol isopropílico
- **Verificación:** Calibrar cada mes o ante lecturas anómalas
- **Almacenamiento:** Guardar en lugar seco cuando no se use

---

## Solución de Problemas

### WiFi

#### ❌ ESP32 no se conecta a WiFi

**Síntomas:**
- LCD muestra "Conectando WiFi..." indefinidamente
- Serial: "❌ Error: No se pudo conectar a WiFi"

**Soluciones:**

1. **Verificar credenciales:**
   ```cpp
   const char* WIFI_SSID = "NOMBRE_EXACTO";
   const char* WIFI_PASSWORD = "contraseña_exacta";
   ```

2. **Verificar frecuencia de red:**
   - ESP32 solo soporta 2.4 GHz
   - Desactivar temporalmente banda 5 GHz del router

3. **Verificar rango de señal:**
   ```cpp
   Serial.print("Señal: ");
   Serial.print(WiFi.RSSI());
   Serial.println(" dBm");
   // Ideal: > -50 dBm
   // Bueno: -50 a -70 dBm
   // Malo: < -70 dBm
   ```

4. **Reset WiFi manual:**
   ```cpp
   WiFi.disconnect(true);
   delay(1000);
   WiFi.begin(WIFI_SSID, WIFI_PASSWORD);
   ```

#### Conecta pero pierde conexión

**Solución:** La función `verificarWiFi()` ya maneja reconexión automática cada 30s.

### UDP

#### Dashboard no recibe datos

**Checklist:**

1. ✅ **Firewall de Windows:**
   ```cmd
   # Verificar reglas
   netsh advfirewall firewall show rule name=all | findstr "1880"
   
   # Si no existe, crear regla
   netsh advfirewall firewall add rule name="Node-RED UDP 1880" dir=in action=allow protocol=UDP localport=1880
   ```

2. ✅ **IP correcta:**
   ```cpp
   // En main.cpp, verificar que coincide con tu PC
   const char* UDP_SERVER_IP = "192.168.1.100";
   ```
   
   ```cmd
   # Windows: obtener tu IP
   ipconfig | findstr IPv4
   ```

3. ✅ **Node-RED escuchando:**
   ```cmd
   netstat -an | findstr "1880"
   # Debe mostrar: UDP 0.0.0.0:1880
   ```

4. ✅ **Debug en Serial:**
   ```
   📤 Datos enviados por UDP:
   {"timestamp":12345,...}
   ```

5. ✅ **Debug en Node-RED:**
   - Abrir pestaña "Debug"
   - Verificar nodo "🔍 Debug Datos"
   - Debe aparecer el JSON recibido

#### Comandos no llegan al ESP32

**Solución:**

1. Verificar que ESP32 escucha en 1881:
   ```cpp
   Serial.print("🔌 UDP escuchando en puerto: ");
   Serial.println(UDP_LOCAL_PORT);  // Debe ser 1881
   ```

2. En Node-RED, nodo "📤 UDP Salida":
   - Campo "Address": **dejar en BLANCO**
   - Multicast: **broadcast**

3. Test manual:
   ```python
   # Python script para test
   import socket
   import json
   
   sock = socket.socket(socket.AF_INET, socket.SOCK_DGRAM)
   sock.setsockopt(socket.SOL_SOCKET, socket.SO_BROADCAST, 1)
   
   mensaje = json.dumps({"comando": "pausar"})
   sock.sendto(mensaje.encode(), ('<broadcast>', 1881))
   ```

### Sensores

#### Sensor capacitivo da valores constantes

**Diagnóstico:**
```cpp
// En setup(), agregar:
Serial.print("Test ADC GPIO 25: ");
Serial.println(analogRead(25));
// Debe variar entre 0-4095
```

**Causas:**
- Pin no configurado como INPUT
- Sensor desconectado
- Sensor en corto

**Solución:**
```cpp
pinMode(25, INPUT);
analogReadResolution(12);  // 12 bits
```

#### Sensores de turbidez no responden

**Diagnóstico:**
```cpp
int raw1 = sensorTurbidez1.leerRaw();
Serial.println(raw1);  // -1 = error, 0-255 = OK
```

**Causas comunes:**

1. **Baudrate incorrecto:**
   ```cpp
   serial->begin(9600, SERIAL_8N1, pinRx, pinTx);
   ```

2. **Pines RX/TX invertidos:**
   ```
   ESP32 RX → Sensor TX
   ESP32 TX → Sensor RX
   ```

3. **Alimentación insuficiente:**
   - Sensores requieren 5V estable
   - Verificar con multímetro

4. **Comando incorrecto:**
   ```cpp
   unsigned char comandoLectura[5] = {0x18, 0x05, 0x00, 0x01, 0x0D};
   ```

### LCD

#### LCD no detectado

**Diagnóstico:**
```cpp
if (!lcd.detectar()) {
    Serial.println("❌ LCD no detectado");
    // Probar direcciones alternativas
    for (uint8_t addr = 0x20; addr <= 0x27; addr++) {
        Wire.beginTransmission(addr);
        if (Wire.endTransmission() == 0) {
            Serial.print("✅ Dispositivo I2C en: 0x");
            Serial.println(addr, HEX);
        }
    }
}
```

**Direcciones comunes:**
- 0x27 (default)
- 0x3F
- 0x20

**Solución:**
```cpp
LCDDisplay lcd(0x3F, 21, 22);  // Cambiar dirección
```

#### LCD muestra caracteres raros

**Causas:**
- Contraste mal ajustado (potenciómetro en módulo I2C)
- Inicialización fallida

**Solución:**
```cpp
lcd.begin();
delay(100);
lcd.begin();  // Doble inicialización
```

---

</div>

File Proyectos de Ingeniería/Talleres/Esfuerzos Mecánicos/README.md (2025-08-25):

# Informe de Taller – Simulación de Fallas Mecánicas en SimScale

## 1. Título
**Análisis de deformaciones y esfuerzos mecánicos mediante simulación en SimScale**

---

## 2. Objetivos
- Comprender el uso de la plataforma **SimScale** para realizar análisis de esfuerzos y deformaciones en sólidos.  
- Simular distintos tipos de cargas mecánicas (tracción, compresión, corte, etc) aplicadas a un modelo 3D importado desde Onshape.  
- Visualizar gráficamente la deformación y los esfuerzos internos mediante colorimetría y escalas de Von Mises.  
- Interpretar los resultados obtenidos y relacionarlos con los conceptos teóricos de resistencia de materiales.

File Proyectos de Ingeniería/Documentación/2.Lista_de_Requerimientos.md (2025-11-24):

<p align="left">
  
  <h1 align="center">Lista de Requerimientos</h1>
</p>

Proyecto: **Sistema de Monitoreo de Calidad de Aceite de Cocina Reutilizado mediante capacitancia y turbidez**  
Institución: Universidad Peruana Cayetano Heredia  
Fecha Primera Revisión: 18/08/2025  

| Fecha | Tipo | Exigencia | Descripción | Responsable |
|---|---|---|---|---|
| 09/09/25 | E | Función principal | El dispositivo debe medir la calidad del aceite vegetal usado a través de **capacitancia** (relacionado con cambios en la constante dieléctrica del aceite debido a la degradación de sus componentes) y **turbidez** (indicador indirecto de la presencia de impurezas y particulas en suspensión). Ambos parámetros son aceptados en la literatura como indicadores de deterioro. | J.M, J.H, Vanesa R, Victor R, G.O |
| 09/09/25 | E | Funcion secundaria | El dispositivo debe mostrar el nivel de calidad de aceite( Apto/ No apto ) mediante un indicador visual y/o pantalla LCD de forma clara y legible. | Vanesa R, Victor R |
| 09/09/25 | E | Medición de parámetros | **Capacitancia aparente:** rango 0–1000 pF(ajustable segun calibración), resolución ±0.1 pF; alerta si la variación excede valores de referencia establecidos en pruebas experimentales(indicando deterioro). <br> **Turbidez en NTU:** (0-3000) con umbral critico > 500 NTU empleando dispersión de luz para detectar particulas quemadas del aceite. | J.M, J.H, G.O |
| 18/08/25 | E | Geometría y portabilidad | Prototipo compacto y liviano (<1.5 kg). Dimensiones: alto: 23 cm, largo: 21 cm, ancho 11.5 cm diseñado para transporte en mochila y uso en campo (ISO 7250). | Victor R |
| 18/08/25 | D | Energía y autonomía | Autonomía mínima de 8 horas con baterías recargables de bajo costo; salida en corriente continua de 3–5 V. | G.O |
| 09/09/25 | E | Software y control | El sistema debe procesar lecturas de capacitancia, registrar turbidez y estimar NTU, corregir por temperatura y entregar diagnóstico (Apto/No apto). | J.M |
| 05/10/25 | E | Conectividad y registro| Lecturas exportables a un dashboard interactivo vía Bluetooth/Wi-Fi. | Vanesa R |
| 05/10/25 | E | Señales e interfaz | Un indicador visual debe mostrar capacitancia, turbidez y diagnóstico final. | Vanesa R |
| 18/08/25 | E | Ergonomía y operación  | Uso simple con un único botón para medición. Respetar ergonomía (ISO 7250). | G.O |
| 18/08/25 | D | Costo accesible | Costo del prototipo ≤ S/ 350 (sensores, microcontrolador, indicador visual, batería, carcasa). | J.H |
| 18/08/25 | D | Fabricación y resistencia | Carcasa impresa en 3D (PLA/ABS) y acrílico en contacto con el aceite. Cumplir ISO 22000 e ISO 468. | Victor R |
| 18/08/25 | D | Limpieza y mantenimiento | Compartimento de muestras de fácil limpieza manual y fácil mantenimiento de componentes ; incluir manual de usuario. | G.O |
| 18/08/25 | E | Comunicaciones internas | Subsistemas conectados por cableado confiable, evitando interferencias. | Vanesa R |
| 18/08/25 | E | Seguridad | Cumplimiento de Ley N°29783 y norma ISO 45001; incluir botón de encendidoo/apagado manual. | J.H |
| 18/08/25 | D | Fabricación | Materiales accesibles en el mercado local o con importación ≤15 días. Cumplimiento con DS 007-98-SA (DIGESA). | J.H |
| 18/08/25 | E | Control de calidad | Cumplir dimensiones, tolerancias, seguridad, higiene y normativa alimentaria (Codex Alimentarius). | Victor R, Vanesa R |
| 18/08/25 | E | Transporte | Portátil, resistente a vibraciones y protegido para traslado en mochila. | Victor R |
| 18/08/25 | D | Uso ambiental | Operar hasta 3500 m.s.n.m y tolerar variaciones de temperatura y humedad (condiciones del Perú). | Victor R |
| 18/08/25 | E | Plazos | El proyecto empezará el lunes 18 de agosto y finalizará el martes 2 de diciembre con un total aproximado de 128 horas de trabajo. | J.M, J.H, Vanesa R, Victor R, G.O |

## Bibliografía

- Anderson-Negele. (2025, 19 de febrero). Turbidity control in food and beverage production: Overview, applications and selection criteria [White paper]. Anderson-Negele.
  Recuperado de [https://www.anderson-negele.com/wp-content/themes/andersonnegele/assets/whitepaper/Whitepaper_40010_Turbidity-Control-Technology_en.pdf](https://www.anderson-negele.com/wp-content/themes/andersonnegele/assets/whitepaper/Whitepaper_40010_Turbidity-Control-Technology_en.pdf)

- AOCS. (2017). *Official Method Cd 20-91: Total Polar Materials in Used Frying Oils.* American Oil Chemists’ Society.  
  Recuperado de [https://www.aocs.org/resource/determination-of-polar-compounds-in-used-frying-oils-and-fats-by-adsorption-chromatography](https://www.aocs.org/resource/determination-of-polar-compounds-in-used-frying-oils-and-fats-by-adsorption-chromatography)

- Codex Alimentarius. (2019). *Standard for Named Vegetable Oils (CODEX-STAN 210-1999).* FAO/WHO.  
  Recuperado de [http://www.fao.org/fao-who-codexalimentarius/sh-proxy/en/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](http://www.fao.org/fao-who-codexalimentarius/sh-proxy/en/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)
  
- Congreso de la República del Perú. (2011). *Ley N° 29783, Ley de Seguridad y Salud en el Trabajo.*  
  Recuperado de [https://www.gob.pe/institucion/mtpe/normas-legales/203435-ley-n-29783](https://www.gob.pe/institucion/mtpe/normas-legales/203435-ley-n-29783)

- FAO/OMS. (2010). *Safety evaluation of certain food additives and contaminants* (WHO Food Additives Series 61). Geneva: World Health Organization.  
  Recuperado de [https://www.who.int/publications/i/item/9789241660614](https://www.who.int/publications/i/item/9789241660614)

- Haryanto, B., Alexander, V., Nasution, I. T., Polem, A. F., Sitohang, O. M., Tambun, R., & Masyithah, Z. (2023). Environmental sustainability through the utilization of corn cobs as an adsorbent material in waste cooking oil. IOP Conference Series: Earth and Environmental Science, 1241, 012115.
  Recuperado de [https://doi.org/10.1088/1755-1315/1241/1/012115](https://doi.org/10.1088/1755-1315/1241/1/012115)

- ISO. (2020). *ISO 660:2020 – Animal and vegetable fats and oils — Determination of acid value and acidity.*  
  Recuperado de [https://www.iso.org/standard/76623.html](https://www.iso.org/standard/76623.html)

- ISO. (2018). *ISO 22000:2018 – Food safety management systems — Requirements for any organization in the food chain.*  
  Recuperado de [https://www.iso.org/standard/65464.html](https://www.iso.org/standard/65464.html)

- ISO. (2019). *ISO 468:2019 – Surface roughness — Parameters, their values and general rules for specifying requirements.*  
  Recuperado de [https://www.iso.org/standard/69126.html](https://www.iso.org/standard/69126.html)

- ISO. (2017). *ISO 7250-1:2017 – Basic human body measurements for technological design — Part 1.*  
  Recuperado de [https://www.iso.org/standard/65244.html](https://www.iso.org/standard/65244.html)

- ISO. (2018). *ISO 45001:2018 – Occupational health and safety management systems.*  
  Recuperado de [https://www.iso.org/standard/63787.html](https://www.iso.org/standard/63787.html)

- Khaled, A. Y., Aziz, S. A., & Rokhani, F. Z. (2015). Capacitive sensor probe to assess frying oil degradation. *Information Processing in Agriculture, 2*(2), 142–148.
  Recuperado de [https://doi.org/10.1016/j.inpa.2015.07.002](https://doi.org/10.1016/j.inpa.2015.07.002)

- Ministerio de Salud del Perú. (1998). *Decreto Supremo N° 007-98-SA, Reglamento sobre Vigilancia y Control Sanitario de Alimentos y Bebidas.*  
  Recuperado de [https://www.gob.pe/institucion/minsa/normas-legales/287047-007-98-sa](https://www.gob.pe/institucion/minsa/normas-legales/287047-007-98-sa)

- Srkar, D., Vasudeva Reddy, T., Anirudh Reddy, R., Siri, B., Lahari, B., & Sangeetha Rani, E. (2025). Cooking oil purity and reusability detection system using embedded system. E3S Web of Conferences, 648, Article 03028.
  Recuperado de [https://doi.org/10.1051/e3sconf/202564803028](https://doi.org/10.1051/e3sconf/202564803028)

- Zhang, Z., Li, Z., Zhang, X., Zhou, J., Wang, S., & Chen, Y. (2020). Portable dielectric sensor for frying oil monitoring. *Sensors, 20*(3), 837.
  Recuperado de [https://doi.org/10.3390/s20030837](https://doi.org/10.3390/s20030837)

- Zubair, M., Kim, H. S., & Kim, H. S. (2018). Capacitive sensor for engine oil deterioration measurement. *Sensors and Transducers, 219*(7), 1–8.  
  Recuperado de [https://www.sensorsportal.com/HTML/DIGEST/july_2018/P_3098.pdf](https://www.sensorsportal.com/HTML/DIGEST/july_2018/P_3098.pdf)

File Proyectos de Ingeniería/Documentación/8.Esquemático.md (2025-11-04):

<p align="left">
  
</p>

# Esquemático del sistema electrónico — *SafeFry*

El siguiente diagrama muestra el esquemático general del dispositivo SafeFry, diseñado en EasyEDA.  
Incluye la integración del **ESP32 WROOM 30P**, el **módulo de carga TP4056**, el **convertidor DC-DC Boost XL6009E1**, los sensores de **turbidez** y **capacitancia**, dos botones de medición y el módulo de pantalla LCD I2C.

Este diseño representa la arquitectura electrónica base del prototipo, enfocada en la medición de la calidad del aceite vegetal mediante parámetros de **turbidez y capacitancia**, optimizando el consumo energético mediante una batería recargable de 3.7 V.

<p align="center">
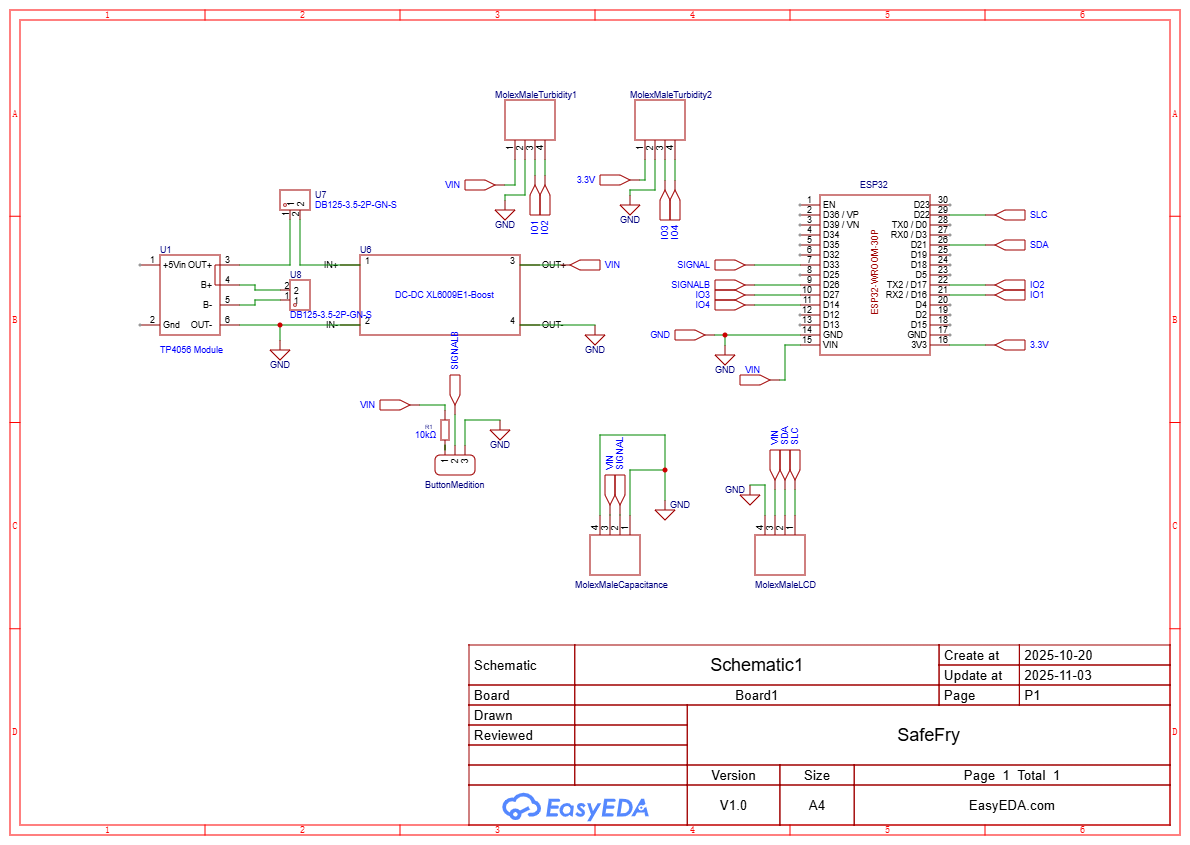
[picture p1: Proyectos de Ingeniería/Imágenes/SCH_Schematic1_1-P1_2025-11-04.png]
  
</p>

*Figura 1. Diagrama esquemático del prototipo SafeFry en EasyEDA.*

---

<p align="center">
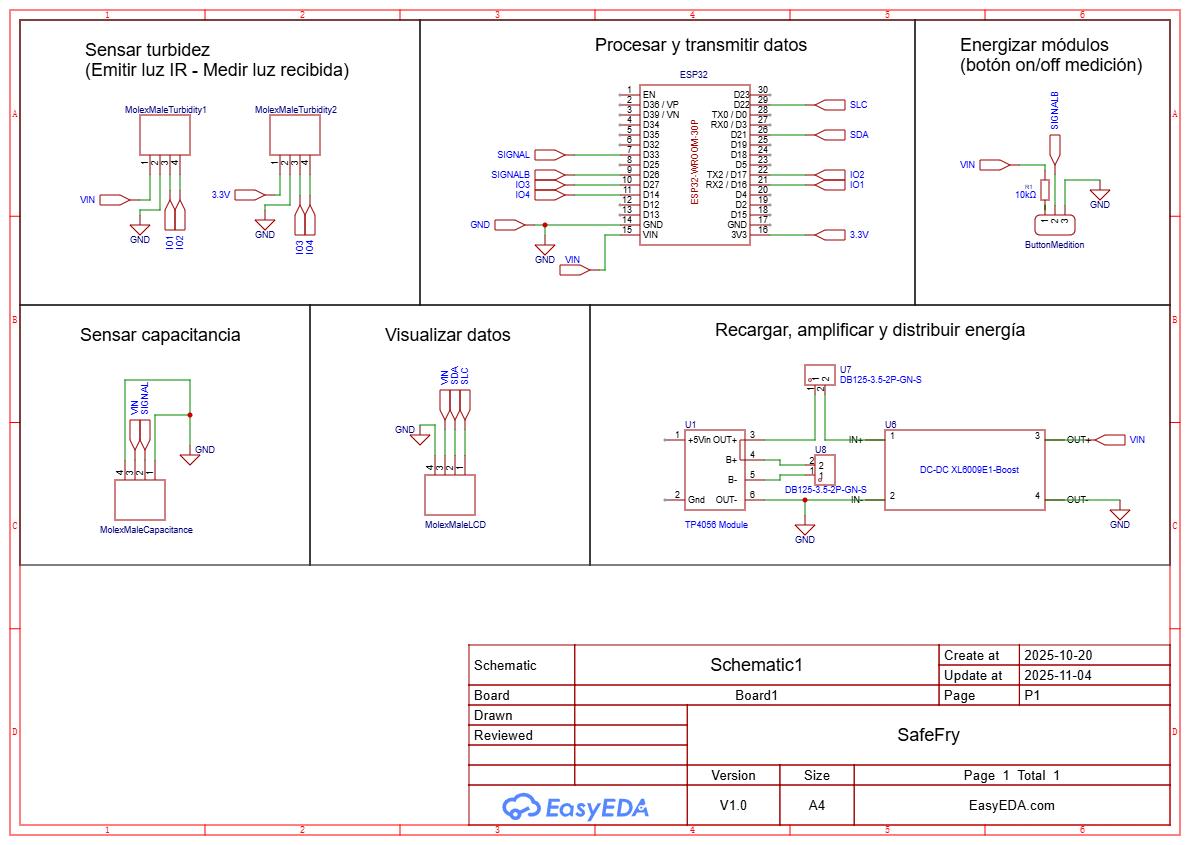
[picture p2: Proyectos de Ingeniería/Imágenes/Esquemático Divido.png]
  
</p>

*Figura 2. Diagrama esquemático divido por regiones de procesamiento.*

---

# PCB — *SafeFry*
<p align="center">
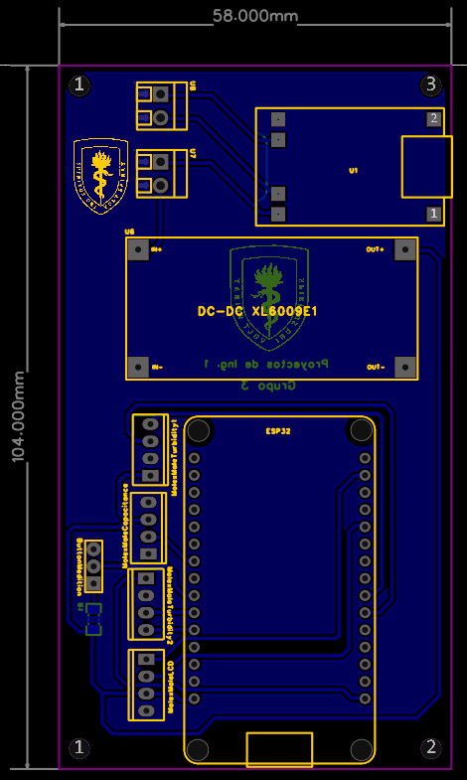
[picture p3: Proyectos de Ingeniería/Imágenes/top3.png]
  
</p>

*Figura 3. Top Layer.*

<p align="center">
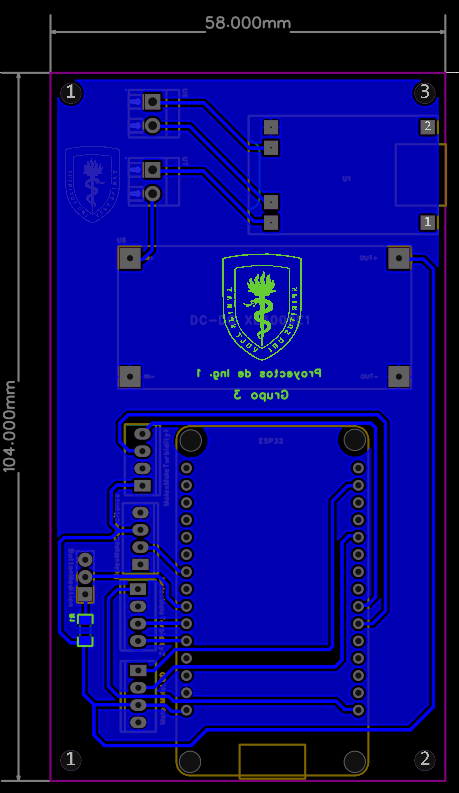
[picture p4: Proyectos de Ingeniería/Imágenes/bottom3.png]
  
</p>

*Figura 4. Bottom Layer.*

---

# Modelo 3D interactivo del PCB — *SafeFry*

[Ver modelo interactivo en Sketchfab](https://skfb.ly/pCVZW)

<p align="center">
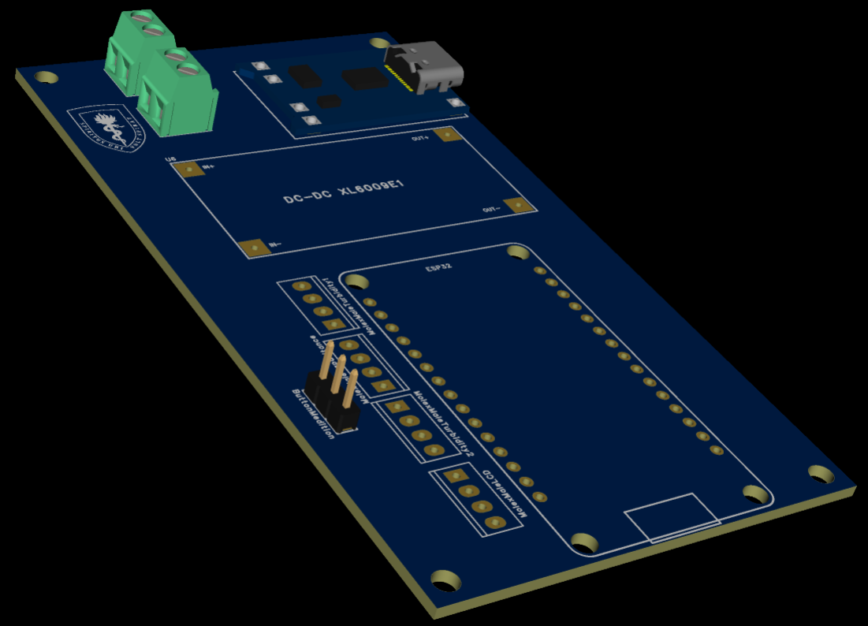
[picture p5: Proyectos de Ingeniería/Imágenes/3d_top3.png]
  
</p>

<p align="center">
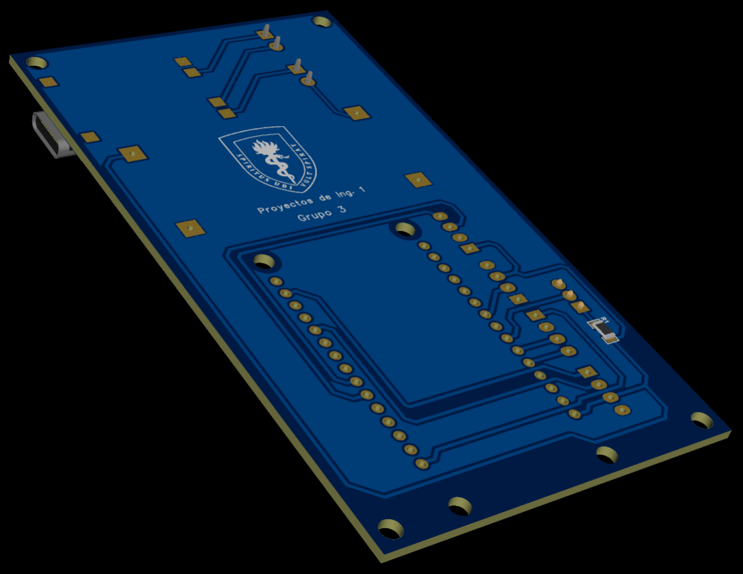
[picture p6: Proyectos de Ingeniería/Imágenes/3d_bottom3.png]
  
</p>

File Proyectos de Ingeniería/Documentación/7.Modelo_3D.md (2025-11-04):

<p align="left">
  
</p>

# Modelo 3D del Prototipo SafeFry

Link de OneShape: https://cad.onshape.com/documents/33e2e4672be8dc7ec5e8ae09/w/13b6d7be983be934564895bf/e/6dd204cf2977ec522326948d

- El modelo tridimensional del prototipo SafeFry fue desarrollado en Onshape para representar el diseño físico del dispositivo medidor de calidad de aceite vegetal.  
- El conjunto está conformado por tres piezas principales: la carcasa, el porta-muestra, tapa superior y lateral.  
- Cada una se diseñó para cumplir una función específica y facilitar el ensamblaje del circuito y los sensores.

---

## 1. Carcasa principal

La carcasa contiene la base donde se fija el sistema electrónico. En su interior se incluyen soportes para el PCB, la batería y los sensores, además de orificios de sujeción y espacio para el cableado.  
El diseño busca ser compacto, modular y fácil de imprimir en 3D.

Vista isométrica 1:

<p align="center">
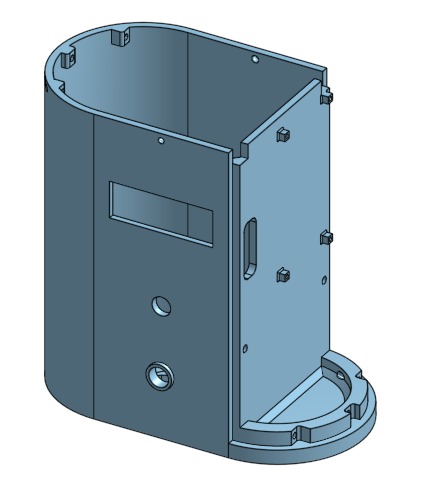
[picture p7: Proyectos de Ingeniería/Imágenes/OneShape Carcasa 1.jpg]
  
</p>

Vista frontal:

<p align="center">
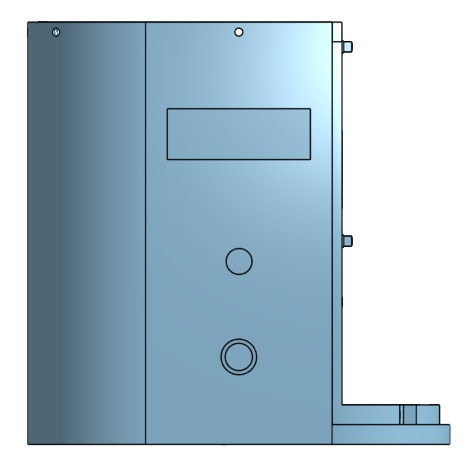
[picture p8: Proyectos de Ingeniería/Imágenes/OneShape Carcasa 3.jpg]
  
</p>

Vista lateral derecha:

<p align="center">
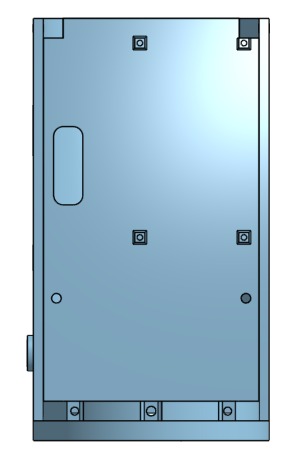
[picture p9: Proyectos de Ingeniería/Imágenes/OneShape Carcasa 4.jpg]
  
</p>

Vista posterior:

<p align="center">
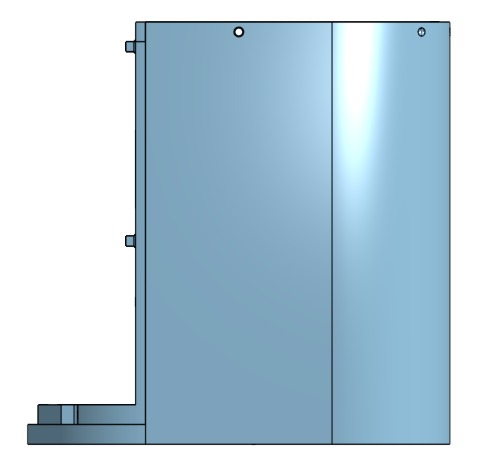
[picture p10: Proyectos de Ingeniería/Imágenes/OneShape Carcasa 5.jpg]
  
</p>

Vista superior:

<p align="center">
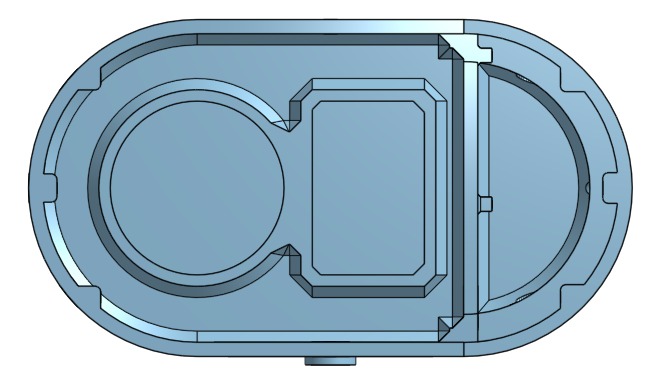
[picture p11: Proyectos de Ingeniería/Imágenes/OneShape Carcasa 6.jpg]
  
</p>

Vista isométrica 2:

<p align="center">
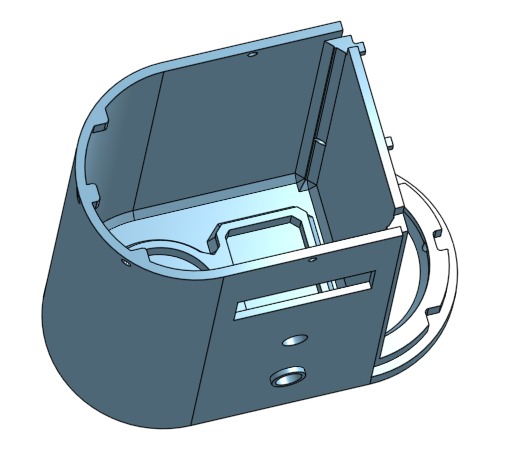
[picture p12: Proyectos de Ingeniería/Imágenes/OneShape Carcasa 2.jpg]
  
</p>

Plano técnico:

<p align="center">
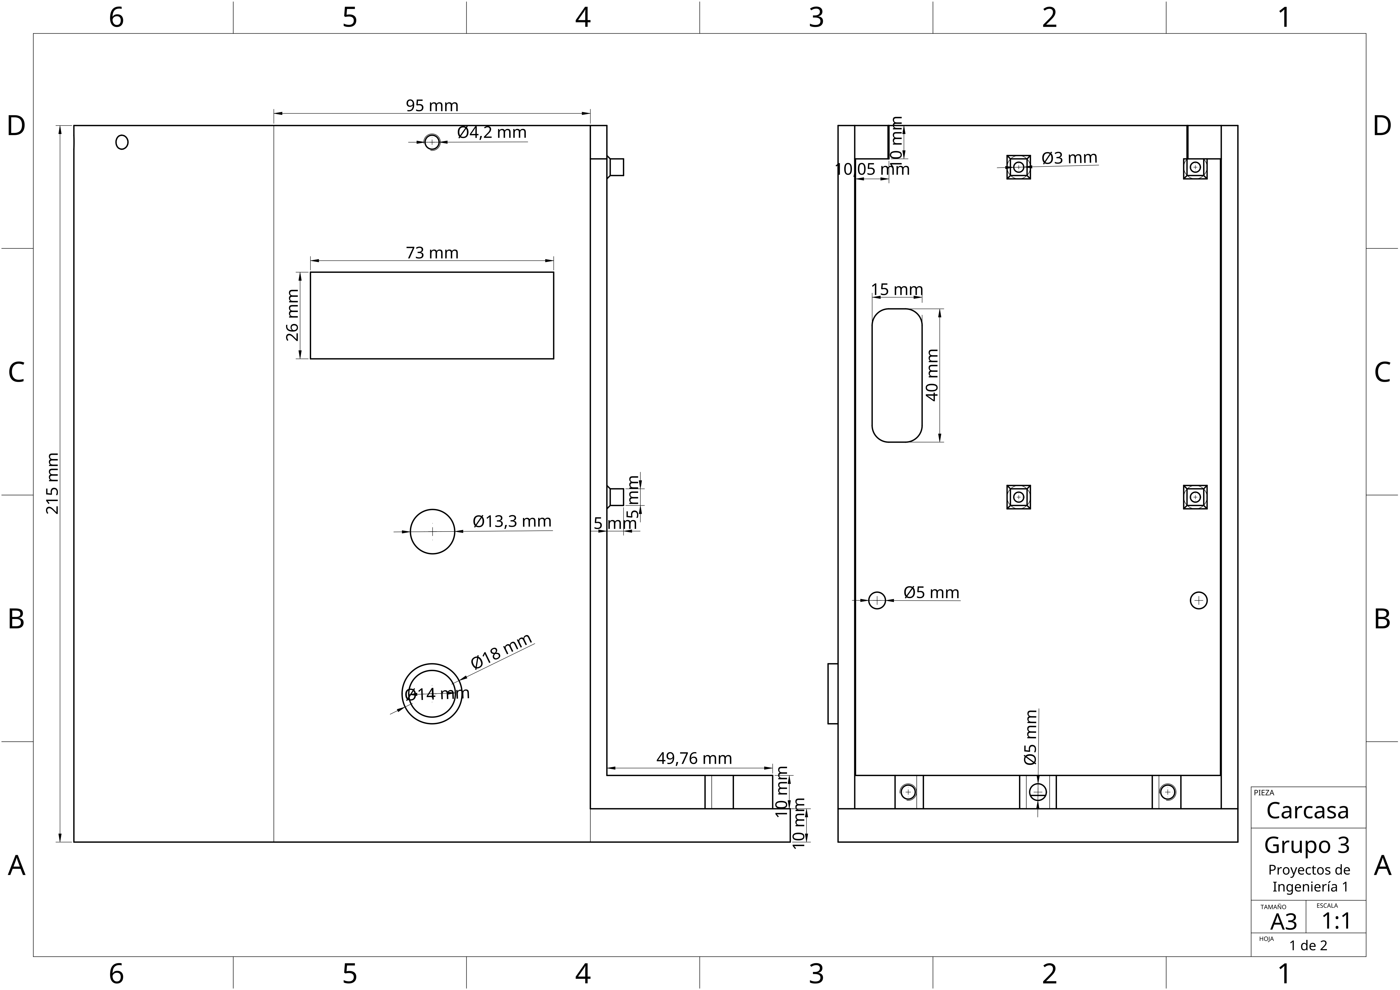
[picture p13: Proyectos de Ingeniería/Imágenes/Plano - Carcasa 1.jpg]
  
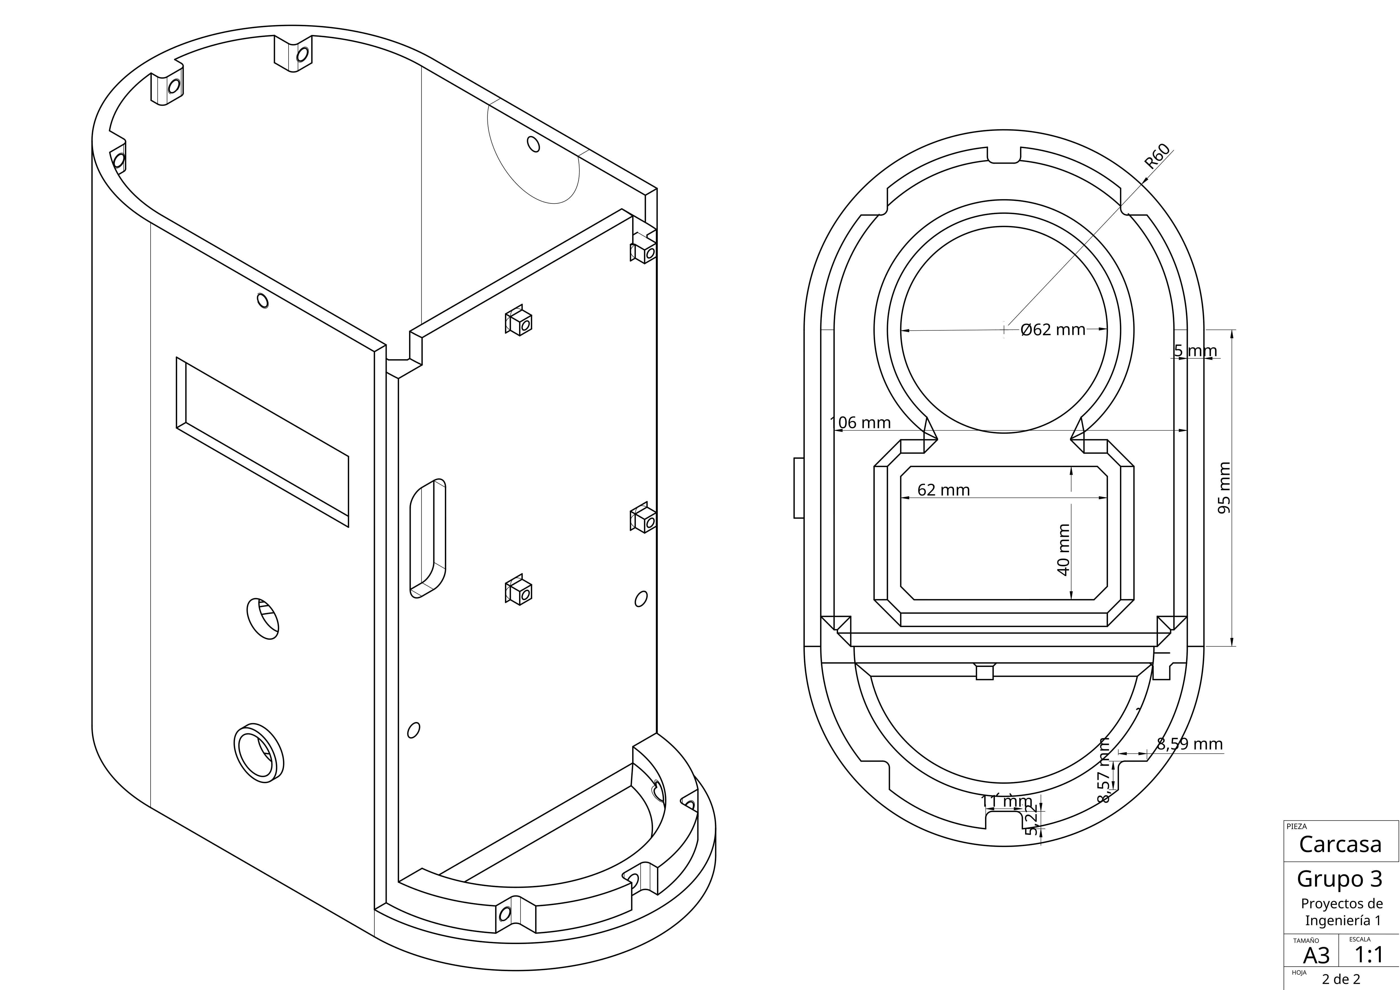
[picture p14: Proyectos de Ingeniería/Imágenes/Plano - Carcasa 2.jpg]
  
</p>

---

## 2. Porta-muestra

En el porta-muestra se deposita el aceite para el análisis.  
Mantiene alineadas las sondas del sensor de turbidez y el sensor capacitivo, asegurando una medición estable y repetible.

Vista isométrica:

<p align="center">
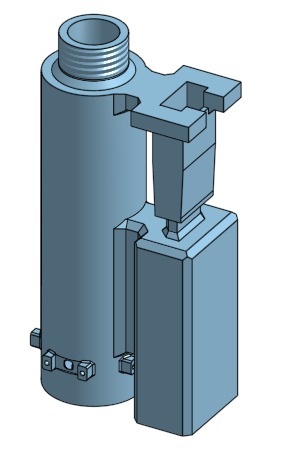
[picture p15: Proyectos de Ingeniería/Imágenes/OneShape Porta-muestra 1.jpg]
  
</p>

Vista frontal:

<p align="center">
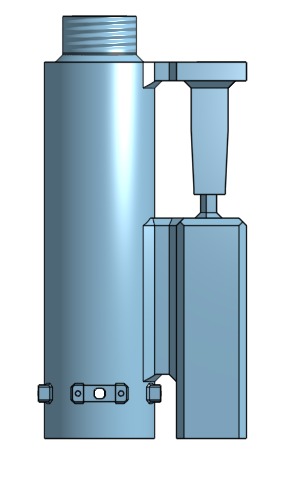
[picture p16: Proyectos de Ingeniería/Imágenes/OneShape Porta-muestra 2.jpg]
  
</p>

Vista lateral izquierda:

<p align="center">
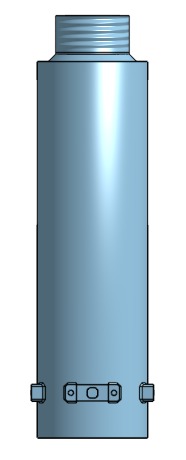
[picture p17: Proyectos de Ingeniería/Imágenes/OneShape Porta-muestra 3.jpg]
  
</p>

Vista lateral derecha:

<p align="center">
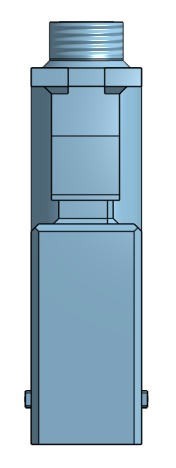
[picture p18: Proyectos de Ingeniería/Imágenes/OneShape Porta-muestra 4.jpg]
  
</p>

Plano técnico:

<p align="center">
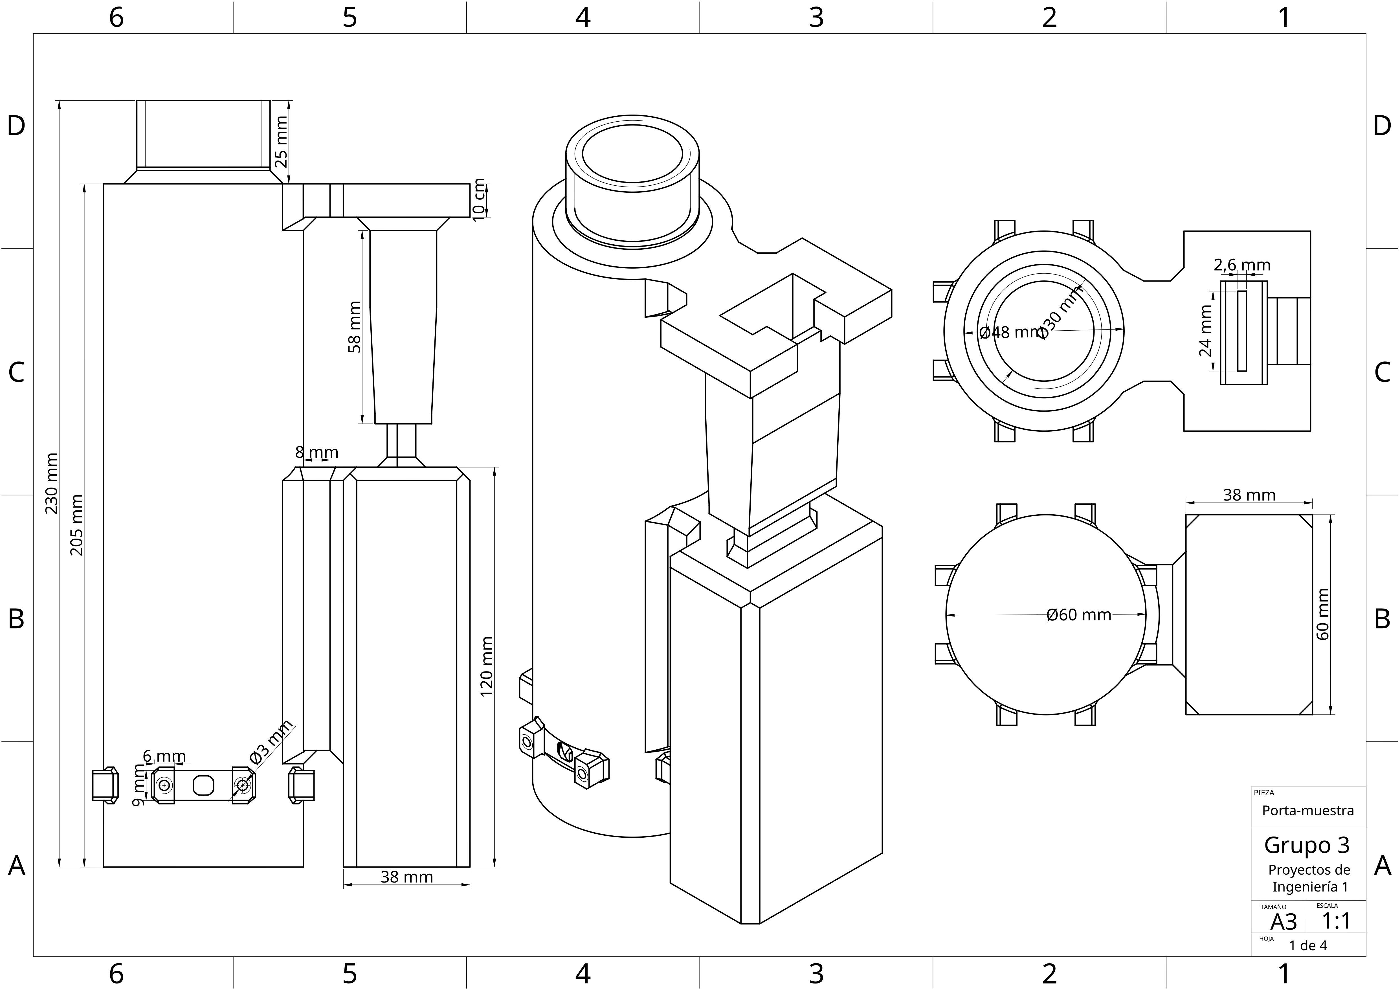
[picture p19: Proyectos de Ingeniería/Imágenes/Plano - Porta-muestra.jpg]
  
</p>

---

## 3. Tapa superior

La tapa protege los componentes internos y permite cerrar el sistema de forma segura.  
Incluye un acople lateral que cubre el espacio del porta-muestra y los sensores, manteniendo el dispositivo sellado pero accesible para mantenimiento o calibración.

Vista isométrica 1:

<p align="center">
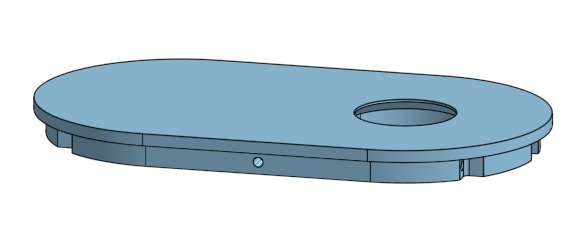
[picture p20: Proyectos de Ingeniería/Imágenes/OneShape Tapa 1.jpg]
  
</p>

Vista frontal:

<p align="center">
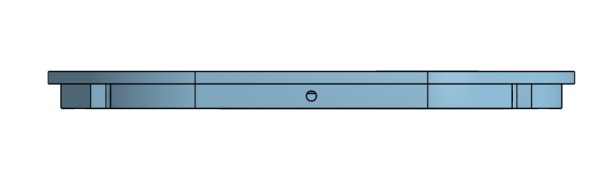
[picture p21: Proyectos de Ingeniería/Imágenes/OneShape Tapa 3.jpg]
  
</p>

Vista interior:

<p align="center">
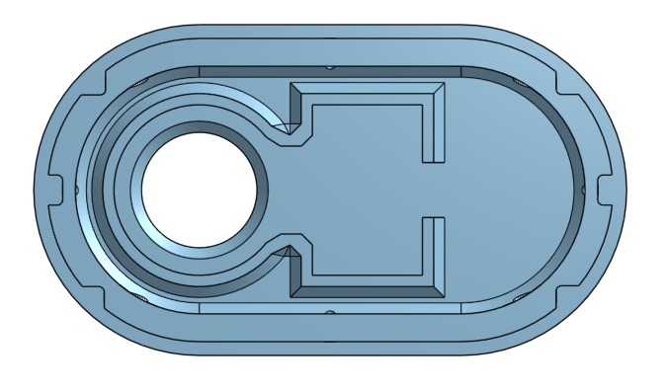
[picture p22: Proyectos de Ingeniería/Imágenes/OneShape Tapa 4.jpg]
  
</p>

Vista isométrica 2:

<p align="center">
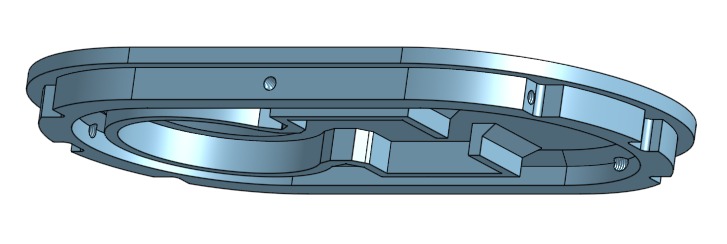
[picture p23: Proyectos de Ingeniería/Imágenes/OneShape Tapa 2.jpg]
  
</p>

Plano técnico:

<p align="center">
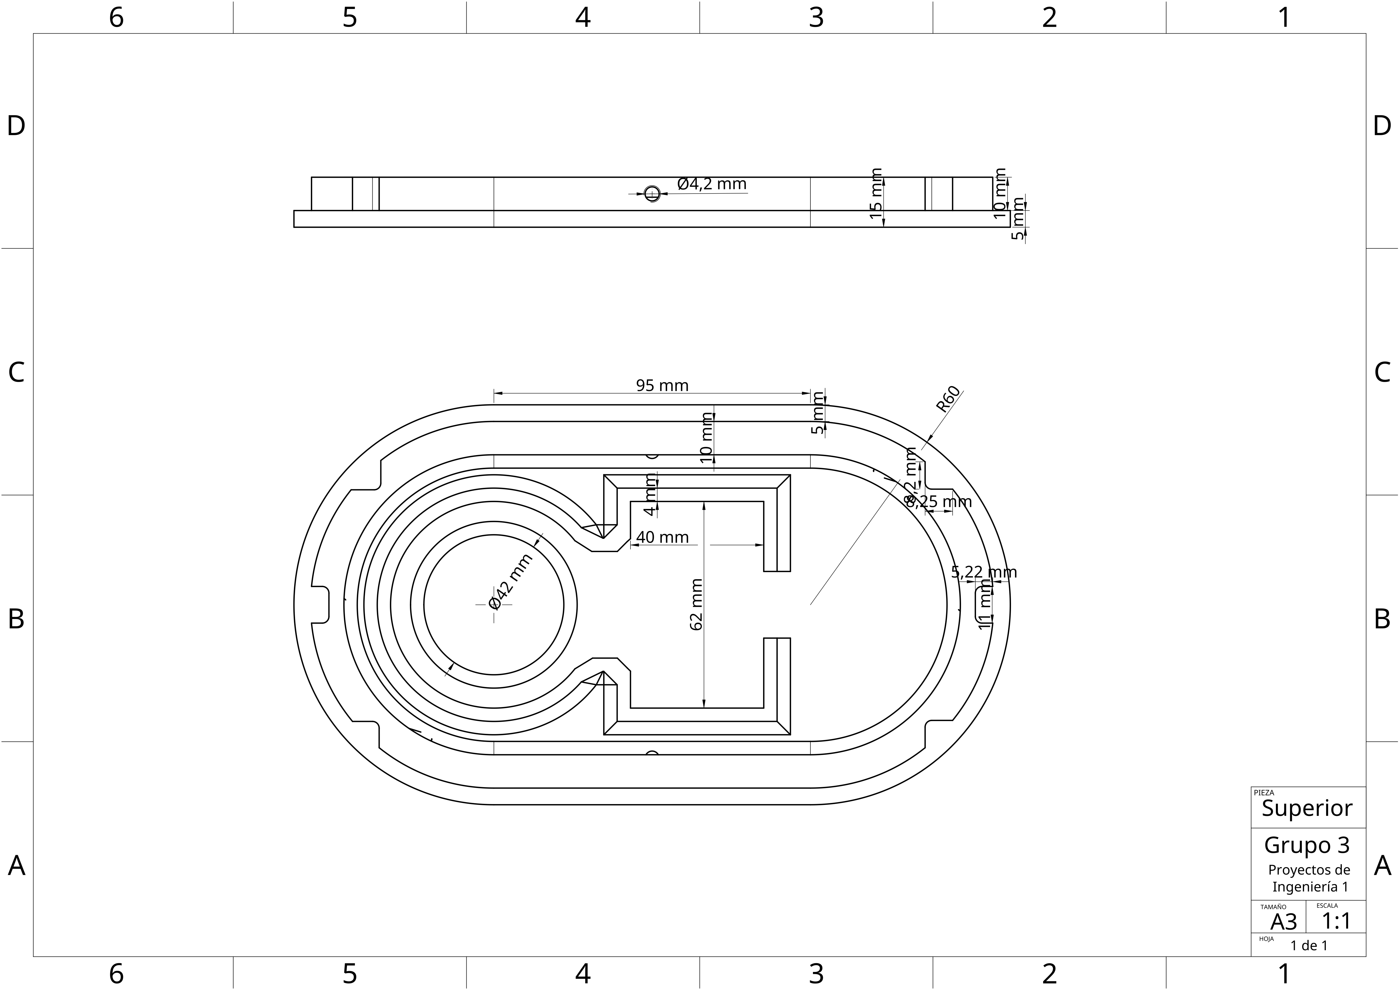
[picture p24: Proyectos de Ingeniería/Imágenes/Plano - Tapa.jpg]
  
</p>

---

## 4. Tapa Lateral

La vista lateral del conjunto permite observar la disposición general del sistema una vez ensamblado.  
Muestra la posición del porta-muestra, la tapa y la carcasa, además del espacio reservado para los módulos electrónicos.

Vista isométrica:

<p align="center">
  
</p>

Vista lateral izquierda:

<p align="center">
  
</p>

Vista lateral derecha:

<p align="center">
  
</p>

Vista inferior:

<p align="center">
  
</p>

Plano técnico:

<p align="center">
  
</p>

---

## 5. Comentarios finales

El modelado 3D permitió validar la compatibilidad entre las piezas, verificar los espacios internos y optimizar el ensamblaje antes de la impresión.  
Con este diseño se garantizó la correcta integración del sistema electrónico, los sensores y la estructura del prototipo SafeFry.

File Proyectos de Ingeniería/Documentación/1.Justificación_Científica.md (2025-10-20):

<p align="left">
  
  <h1 align="center">Justificación Científica :  Uso de Sensores de Capacitancia y Turbidez en la Evaluación de la Calidad del Aceite</h1>
</p>

## Introducción

El deterioro del aceite vegetal durante su uso repetido en procesos de fritura produce una serie de **cambios físico-químicos** que alteran su estructura molecular, densidad, constante dieléctrica y transparencia óptica. Estos cambios son resultado de fenómenos como la **oxidación, hidrólisis y polimerización** de los ácidos grasos, los cuales afectan directamente la calidad del aceite y, por ende, la inocuidad de los alimentos elaborados con él.

Para evaluar estos procesos de degradación sin recurrir a métodos de laboratorio costosos, se han explorado dos principios físicos complementarios:  
- la **capacitancia dieléctrica**, sensible a la variación de la permitividad eléctrica del aceite, y  
- la **turbidez óptica**, dependiente de la dispersión de luz causada por partículas, residuos y contaminantes suspendidos.

Diversas investigaciones respaldan esta aproximación.
A continuación, se presentarán **estudios científicos y desarrollos tecnológicos** que demuestran la validez del uso de la **capacitancia y la turbidez** como indicadores confiables para determinar la calidad del aceite vegetal, así como su implementación en sistemas embebidos, sensores ópticos y soluciones industriales de monitoreo continuo.

---

### 1. Sistema de detección de pureza y reutilización de aceite de cocina mediante sistema integrado (2025)
https://doi.org/10.1051/e3sconf/202564803028

Este trabajo presenta un sistema embebido que utiliza sensores de capacitancia y temperatura para evaluar la pureza y posibilidad de reutilización del aceite de cocina.
El principio se basa en que la constante dieléctrica del aceite cambia conforme aumenta la cantidad de impurezas o agua residual tras sucesivos ciclos de fritura.
El proyecto demuestra que los sensores capacitivos pueden integrarse con microcontroladores para generar una lectura automatizada y en tiempo real de la calidad del aceite, validando su uso en contextos industriales y domésticos.

<p align="center">
  
</p>
Imagen 1: Diagrama de conectividad de la pureza del aceite de cocina. La luz verde indica que el aceite puede ser reutilizable.

---

### 2. Sostenibilidad ambiental mediante el uso de mazorcas de maíz como material adsorbente en aceite de cocina usado (2023)
https://doi.org/10.1088/1755-1315/1241/1/012115

Este estudio aborda la recuperación del aceite de cocina usado mediante adsorbentes naturales (mazorcas de maíz), pero incluye una evaluación detallada de parámetros físico-químicos, entre ellos la turbidez y la conductividad.
Se demuestra que la turbidez aumenta proporcionalmente con la degradación del aceite, reflejando la acumulación de residuos carbonizados y contaminantes polares, y que su reducción refleja una mejora en la calidad del aceite.
El uso de la turbidez como métrica cuantitativa de impurezas suspendidas refuerza su aplicación en sistemas de monitoreo de aceite, especialmente para procesos de filtración o control de recirculación.

<p align="center">
  
</p>
Imagen 2: Gráfica de turbidez vs tiempo con masa adsorbente de 4 gramos y velocidad de 70 rpm

---

### 3. Control de turbidez en la producción de alimentos y bebidas (2025)
https://www.anderson-negele.com/wp-content/themes/andersonnegele/assets/whitepaper/Whitepaper_40010_Turbidity-Control-Technology_en.pdf

Este documento técnico de la empresa Anderson-Negele expone los principios de medición de turbidez en procesos industriales alimentarios, incluyendo bebidas, lácteos y aceites.
Explica cómo los sensores ópticos de turbidez permiten detectar contaminaciones, emulsiones o mezclas no homogéneas, midiendo la dispersión de luz causada por partículas suspendidas.
Además, detalla los rangos de medición y materiales compatibles para fluidos aceitosos, lo que confirma la viabilidad del control por turbidez en líquidos grasos.

<p align="center">
  
</p>
Imagen 3: Ejemplos de valores de turbidez en NTU

---

### 4. Sonda de sensor capacitivo para evaluar la degradación del aceite de freír (2015)
https://doi.org/10.1016/j.inpa.2015.07.002

Este estudio propone un sensor capacitivo con electrodos interdigitados (IDE) para monitorear la degradación del aceite de fritura midiendo cambios en la capacitancia con el tiempo de calentamiento. Se realizaron pruebas con 30 muestras de aceite de palma calentadas a 180 °C en intervalos hasta 30 h. Los autores midieron la capacitancia eléctrica, los compuestos polares totales (TPC) y la viscosidad de cada muestra, encontrando una correlación significativa entre la capacitancia y el TPC (R² de 0,83 a 0,90) así como con la viscosidad (R² hasta 0,87). Los resultados muestran que la capacitancia puede servir como método simple y económico para estimar la calidad del aceite.

<p align="center">
  
</p>
Imagen 4: Medidas de capacitancia y TPC a 100  kHz en diferentes tiempos de calentamiento.

---

### 5. Evaluación del aceite de freír mediante un sensor portátil basado en la medición de la constante dieléctrica (2019)
https://doi.org/10.3390/s19245375

Este estudio desarrolla un sensor portátil capacitivo usando electrodos interdigitados (IDE) para evaluar la degradación del aceite de fritura mediante mediciones de capacitancia eléctrica. Los autores establecen una correlación preliminar entre la capacitancia medida y los compuestos polares totales (TPM) del aceite, así como con la viscosidad. Demuestran que el dispositivo es liviano, económico y adecuado para pruebas rápidas in situ.

<p align="center">
  
</p>
Imagen 5: Relación entre capacitancia y el tiempo de fritura

---

### 6. Sensor y metodología para el análisis dieléctrico de aceites vegetales sometidos a estrés térmico (2015)
https://doi.org/10.3390/s151026457

En este trabajo se presenta un sensor capacitivo y metodología rápida para analizar la degradación del aceite vegetal sometido a estrés térmico, mediante la medición de su constante dieléctrica. Los autores correlacionaron los valores dieléctricos con parámetros físico-químicos como el índice de acidez, índice de yodo, viscosidad y índice de refracción. El estudio muestra que la constante dieléctrica del aceite tiende a incrementarse con el tiempo y temperatura de calentamiento, reflejando un deterioro progresivo.

<p align="center">
  
</p>
Imagen 6: Relación entre la constante dieléctrica y los ciclos de calentamiento

De esta forma, la combinación de ambos parámetros —**capacitancia** y **turbidez**— constituye una solución científica y técnicamente fundamentada para el **monitoreo integral de la calidad del aceite vegetal**, permitiendo un diagnóstico rápido, continuo y reproducible en entornos de uso doméstico o industrial.

---

<p align="left">
  <h1 align="center">Proyectos Referenciales</h1>
</p>

### 1. Un monitor de turbidez continuo de bajo costo
https://doi.org/10.3390/s19143039

Los autores diseñan un monitor continuo de turbidez óptico de bajo costo, usando LED y fotodiodo en una pequeña celda de flujo, obteniendo una resolución alrededor de 1 NTU en el rango de 0-100 NTU. Realizan una prueba de larga duración (38 días) y reportan estabilidad, sensibilidad a variaciones de turbidez y algunas fuentes de error como burbujas y luz ambiente.

<p align="center">
  
</p>
Imagen 7: Estructura circuito de prueba y arquitectura

### 2. Analog Devices – Shield Arduino para mediciones de turbidez críticas, precisas, robustas y sin contacto (EVAL-CN0409-ARDZ) (2018)
https://duino4projects.com/analog-devices-arduino-shield-for-critical-accurate-robust-and-non-contact-turbidity-measurements-eval-cn0409-ardz/

Este proyecto presenta una shield Arduino para medir turbidez sin contacto, basada en el frente óptico ADPD105 con LEDs infrarrojos (~860 nm) y fotodiodos PIN. Soporta estándares ISO 7027 (modo ratio y no ratio), mide en un rango de 0 a 1000 FTU con precisión típica de ±0,50 FTU o ±5 % de la lectura, e incorpora rechazo de luz ambiental.

<p align="center">
  
</p>
Imagen 8: Arquitectura del proyecto

---

## Referencias
1. Gillett, D. & Marchiori, A. (2019). A Low-Cost Continuous Turbidity Monitor. Sensors, 19(14), 3039. https://doi.org/10.3390/s19143039
2. Srkar, D., Vasudeva Reddy, T., Anirudh Reddy, R., Siri, B., Lahari, B., & Sangeetha Rani, E. (2025). Cooking oil purity and reusability detection system using embedded system. E3S Web of Conferences, 648, Article 03028. https://doi.org/10.1051/e3sconf/202564803028
3. Haryanto, B., Alexander, V., Nasution, I. T., Polem, A. F., Sitohang, O. M., Tambun, R., & Masyithah, Z. (2023). Environmental sustainability through the utilization of corn cobs as an adsorbent material in waste cooking oil. IOP Conference Series: Earth and Environmental Science, 1241, 012115. https://doi.org/10.1088/1755-1315/1241/1/012115
4. Anderson-Negele. (2025, 19 de febrero). Turbidity control in food and beverage production: Overview, applications and selection criteria [White paper]. Anderson-Negele. https://www.anderson-negele.com/wp-content/themes/andersonnegele/assets/whitepaper/Whitepaper_40010_Turbidity-Control-Technology_en.pdf
5. Ayyub, I. (2018, 6 de noviembre). Analog Devices – Arduino shield for critical, accurate, robust and non-contact turbidity measurements (EVAL-CN0409-ARDZ). Arduino for Projects. https://duino4projects.com/analog-devices-arduino-shield-for-critical-accurate-robust-and-non-contact-turbidity-measurements-eval-cn0409-ardz/
6. Alkhaled, A. Y., Abd Aziz, S., & Rokhani, F. Z. (2015). Capacitive sensor probe to assess frying oil degradation. Information Processing in Agriculture, 2(2), 142–148. https://doi.org/10.1016/j.inpa.2015.07.002
7. Liu, M., Qin, X., Chen, Z., Tang, L., Borom, B., Cao, N., Barnes, D., Cheng, K., Chen, J., Wang, T., & Rao, J. (2019). Frying Oil Evaluation by a Portable Sensor Based on Dielectric Constant Measurement. Sensors, 19(24), 5375. https://doi.org/10.3390/s19245375
8. Stevan, S. L. Jr., et al. (2015). Sensor and methodology for dielectric analysis of vegetable oils (relating to constant dielectric and degradation). Sensors, 15(10), 26457. https://doi.org/10.3390/s151026457

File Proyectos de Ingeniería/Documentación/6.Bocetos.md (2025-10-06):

<p align="left">
  
</p>

## Boceto 1 – Versión final seleccionada (ESP32)  

<p align="center">
  
</p>

Este diseño representa la propuesta definitiva del dispositivo.  
Su estructura cilíndrica compacta permite alojar los sensores de turbidez y capacitancia dentro de un cuerpo principal fabricado recubierto internamente con enacrílico líquido o resina transparente para protección adicional del prototipo a altas temperaturas (no es recomendable, pero sirve como medida preventiva), materiales resistentes al calor moderado del aceite tibio (30–50 °C). 

**Materiales y fabricación**  
- Cuerpo principal de acrílico líquido transparente o resina epóxica.  
- Soportes internos impresos en 3D con filamento PETG o ABS (resistentes hasta 85 °C).  
- Sección inferior desmontable para reemplazo de baterías.  

**Ventajas**  
- Portátil y ligero.  
- Compatible con los sensores de la matriz morfológica.  
- Buena resistencia térmica y aislamiento eléctrico.  
- Estructura ópticamente adecuada para la lectura del sensor de turbidez.  
- Fabricable con los recursos del laboratorio de ingeniería UPCH.

## Boceto 2 – Versión con Raspberry Pi 5  

<p align="center">
  
</p>

Este diseño explora un enfoque más avanzado, orientado a procesamiento local de datos y almacenamiento interno.  
Mantiene una forma cilíndrica pero incorpora mayor complejidad de hardware.

**Observaciones**  
- Permite procesamiento de datos en el dispositivo.  
- Aumenta el costo, consumo energético y dificultad de ensamblaje.  
- Recomendado para versiones de laboratorio, no para un dispositivo portátil.

## Boceto 3 – Versión con Arduino UNO  

<p align="center">
  
</p>

Prototipo inicial orientado a pruebas de calibración y validación de sensores.  
Tiene estructura rectangular vertical, con compartimentos separados para cada módulo.

**Observaciones**  
- Diseño robusto pero voluminoso.  
- Ideal para prototipos de laboratorio o pruebas de validación.  
- No óptimo para portabilidad.

---

## Modelo 3D preliminar del boceto 1

A partir del boceto seleccionado se desarrolló el modelo 3D preliminar en Onshape, con el objetivo de visualizar la distribución interna de los componentes y validar las proporciones generales del dispositivo.  
El diseño mantiene la forma cilíndrica planteada originalmente, optimizando la integración de los sensores y la accesibilidad para mantenimiento.

<p align="center">
  
</p>

### Características generales del modelo
- Estructura principal cilíndrica impresa en 3D, con base desmontable para acceso a la batería y módulos electrónicos.  
- En la parte frontal se ubica la pantalla LCD y los botones físicos de encendido e inicio de medición, respetando la ergonomía de uso.  
- En el interior se encuentran el ESP32, el módulo de turbidez sin contacto, el sensor capacitivo encapsulado en resina, y el módulo Boost Converter.  
- El contenedor está pensado para recubierto internamente en acrílico líquido, que soporta temperaturas moderadas y permite la correcta lectura óptica del aceite.

### Dimensiones aproximadas
<p align="center">
  
</p>

Estas medidas fueron determinadas considerando la necesidad de alojar los módulos electrónicos y la batería sin comprometer la portabilidad del dispositivo.  
El tamaño final también busca mantener una proporción cómoda para manipular el prototipo en laboratorio y durante pruebas de campo.

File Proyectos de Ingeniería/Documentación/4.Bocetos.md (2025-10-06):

## Boceto 1 – Versión final seleccionada (ESP32)  

<p align="center">
  
</p>

Este diseño representa la propuesta definitiva del dispositivo.  
Su estructura cilíndrica compacta permite alojar los sensores de turbidez y capacitancia dentro de un cuerpo principal fabricado recubierto internamente con enacrílico líquido o resina transparente para protección adicional del prototipo a altas temperaturas (no es recomendable, pero sirve como medida preventiva), materiales resistentes al calor moderado del aceite tibio (30–50 °C). 

**Materiales y fabricación**  
- Cuerpo principal de acrílico líquido transparente o resina epóxica.  
- Soportes internos impresos en 3D con filamento PETG o ABS (resistentes hasta 85 °C).  
- Sección inferior desmontable para reemplazo de baterías.  

**Ventajas**  
- Portátil y ligero.  
- Compatible con los sensores de la matriz morfológica.  
- Buena resistencia térmica y aislamiento eléctrico.  
- Estructura ópticamente adecuada para la lectura del sensor de turbidez.  
- Fabricable con los recursos del laboratorio de ingeniería UPCH.

## Boceto 2 – Versión con Raspberry Pi 5  

<p align="center">
  
</p>

Este diseño explora un enfoque más avanzado, orientado a procesamiento local de datos y almacenamiento interno.  
Mantiene una forma cilíndrica pero incorpora mayor complejidad de hardware.

**Observaciones**  
- Permite procesamiento de datos en el dispositivo.  
- Aumenta el costo, consumo energético y dificultad de ensamblaje.  
- Recomendado para versiones de laboratorio, no para un dispositivo portátil.

## Boceto 3 – Versión con Arduino UNO  

<p align="center">
  
</p>

Prototipo inicial orientado a pruebas de calibración y validación de sensores.  
Tiene estructura rectangular vertical, con compartimentos separados para cada módulo.

**Observaciones**  
- Diseño robusto pero voluminoso.  
- Ideal para prototipos de laboratorio o pruebas de validación.  
- No óptimo para portabilidad.

---

## Modelo 3D preliminar del boceto 1

A partir del boceto seleccionado se desarrolló el modelo 3D preliminar en Onshape, con el objetivo de visualizar la distribución interna de los componentes y validar las proporciones generales del dispositivo.  
El diseño mantiene la forma cilíndrica planteada originalmente, optimizando la integración de los sensores y la accesibilidad para mantenimiento.

<p align="center">
  
</p>

### Características generales del modelo
- Estructura principal cilíndrica impresa en 3D, con base desmontable para acceso a la batería y módulos electrónicos.  
- En la parte frontal se ubica la pantalla LCD y los botones físicos de encendido e inicio de medición, respetando la ergonomía de uso.  
- En el interior se encuentran el ESP32, el módulo de turbidez sin contacto, el sensor capacitivo encapsulado en resina, y el módulo Boost Converter.  
- El contenedor está pensado para recubierto internamente en acrílico líquido, que soporta temperaturas moderadas y permite la correcta lectura óptica del aceite.

### Dimensiones aproximadas
<p align="center">
  
</p>

Estas medidas fueron determinadas considerando la necesidad de alojar los módulos electrónicos y la batería sin comprometer la portabilidad del dispositivo.  
El tamaño final también busca mantener una proporción cómoda para manipular el prototipo en laboratorio y durante pruebas de campo.

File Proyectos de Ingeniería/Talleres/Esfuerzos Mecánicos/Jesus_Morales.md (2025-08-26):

# Simulación Estructural

## Descripción 
Consiste en la simulación estructural de un cajetín diseñado en **Onshape** e importado a **SimScale**.  
El objetivo fue analizar el comportamiento mecánico del modelo al aplicarle una fuerza en una dirección específica, verificando el desplazamiento y la distribución de esfuerzos.

## Configuración de la Simulación

- **Software utilizado:** SimScale (análisis estático lineal).
- **Geometría:** Cajetín importado desde Onshape.
- **Material:** PLA (Polylactic Acid).
- **Condiciones de frontera:**
  - Base del cajetín fijada (restricción total de desplazamientos).
  - Fuerza aplicada en el eje **X** con magnitud de **500 N**.
- **Mallado:** Generado automáticamente con refinamiento estándar.

## Resultados

La simulación permitió visualizar:
- El **mapa de desplazamientos**, que muestra la deformación bajo la carga aplicada.
- La **distribución de esfuerzos de Von Mises**, que permite identificar zonas críticas en el cajetín.
- Se realizó 3 pruebas de estiramiento y compresión, aplicando 500N, las imagenes se encuentran en evidencias.

Se observa que las zonas de mayor concentración de esfuerzos se encuentran alrededor del área cercana a la fijación, mientras que el resto del cuerpo presenta esfuerzos menores.

## Evidencias

A continuación se presentan las capturas de cada etapa y del resultado final de la simulación:

###  Paso 1 – Importación del modelo desde Onshape


###  Paso 2 – Definición de material




###  Paso 3 – Condiciones de frontera




###  Paso 4 – Generación de malla


###  Resultado final – Mapa de calor






## Conclusiones

- El cajetín fabricado en PLA resiste adecuadamente la carga de **500 N** en dirección X, presentando deformaciones dentro de un rango esperado para el material.  
- La fijación en la base es la zona crítica, por lo que en un diseño real se recomienda reforzar esta área para evitar concentraciones excesivas de tensión.  
- El análisis confirma la utilidad de **SimScale** para la validación inicial de diseños provenientes de **Onshape**.

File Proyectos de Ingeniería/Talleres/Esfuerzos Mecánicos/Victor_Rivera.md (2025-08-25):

[Victor Rivera.pdf](https://github.com/user-attachments/files/21977142/Victor.Rivera.pdf)

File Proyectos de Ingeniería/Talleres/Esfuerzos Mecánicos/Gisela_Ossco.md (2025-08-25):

SIMULACION ESTRUCTURAL 

Se diseño una tobera en Onshape y posteriormente se importo a SimScale para realizar un analisis mecanico. El objetivo principal fue evaluar su comportamiento estructural al aplicarle una fuerza en una dirección especifica. Durante la simulación se verifico el desplazamiento resultante y la distribucion de esfuerzos en el material, con el fin de identificar las zonas criticas. 

OBJETIVOS

- Analizar la respuesta estructural de la tobera frente a una fuerza aplicada. 
- Identificar el desplazamiento maximo producido en la geometria. 
- Observar la distribución de tensiones de Von Mises para detectar las zonas de mayor concentración de esfuerzos.
- Validar la resistencia mecanica del diseño y comprobar su viabilidad para condiciones. 

EQUIPOS Y SOFTWARE

- Onshape: para el diseño CAD de la tobera.
- SimScale: Para la simulación estructural

EVIDENCIAS 

A continuacion se adjuntas las imagenes. 























CONCLUSIONES 
-  La simulación mostro que las mayores tensiones se concentran en la parte superior de la tobera
-  El desplazamiento maximo fue bajo, indicando buena rigidez estructural.
-  El diseño es mecanicamente estable bajo la carga aplicada.
-  La integración de Onshape y SinScale permitio evaluar el diseño de forma eficiente.

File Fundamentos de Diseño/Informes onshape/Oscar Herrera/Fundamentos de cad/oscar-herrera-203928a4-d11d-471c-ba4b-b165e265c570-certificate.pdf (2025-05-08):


Oscar Herrera

May 08, 2025

Onshape Assemblies

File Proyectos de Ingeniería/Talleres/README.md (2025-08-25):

# Talleres – Proyectos de Ingeniería 1

En esta sección se presentarán todos los **talleres de laboratorio** desarrollados a lo largo del curso de **Proyectos de Ingeniería 1**.  

Cada taller estará organizado en carpetas independientes, donde se incluirá toda la información correspondiente al tema tratado.  

Dentro de cada carpeta, cada integrante del equipo desarrollará su informe individual en un archivo con extensión `.md`, identificándose con su nombre.  

De esta manera se mantendrá una estructura clara, organizada y colaborativa para el seguimiento de los avances del curso.

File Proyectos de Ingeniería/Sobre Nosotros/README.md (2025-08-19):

<p align="left">
  
  <h1 align="center">Sobre Nosotros</h1>
</p>

## Equipo Actual

| Miembro | Rol | Función Principal | Correo |
| :---: | :---: | :---: | :---: |
| **Rivera Torres Victor Daniel** | Desarrollo Técnico | Prototipado y desarrollo técnico | victor.rivera@upch.pe |
| **Morales Alvarado Jesús Anselmo** | Desarrollo Técnico | Prototipado y desarrollo técnico | jesus.morales@upch.pe |
| **Rioja Cruz Vanesa Doris** | Investigación | Investigación sobre energías renovables | vanesa.rioja@upch.pe |
| **Oscco Pizarro Gisela** | Investigación | Investigación sobre energías renovables | gisela.oscco@upch.pe |
| **Huamani Salazar Jander** | Investigación | Investigación sobre energías renovables | jander.huamani@upch.pe |

## Equipo Fundador

| Miembro | Rol | Función Principal | Correo |
| :---: | :---: | :---: | :---: |
| **Rabanal Bravo Flavio Francisco** | Coordinador General | A cargo de la organización del proyecto | flavio.rabanal@upch.pe |
| **Rivera Torres Victor Daniel** | Coordinador de Diseño y Prototipado | Elaboración de los mapas de construcción | victor.rivera@upch.pe |
| **Herrera Tumba Oscar Manuel** | Coordinador de Investigación | Asegurar datos reales y técnicamente correctos | oscar.herrera@upch.pe |
| **Villamizar Maravi Andrea Margarita** | Coordinadora de Electrónica y Manufactura | Integrar sistemas electrónicos y supervisar pruebas de calidad| andrea.villamizar@upch.pe |
| **Morales Alvarado Jesús Anselmo** | Coordinador de Programación y Página Web | Programar el controlador y visualización digital | jesus.morales@upch.pe |

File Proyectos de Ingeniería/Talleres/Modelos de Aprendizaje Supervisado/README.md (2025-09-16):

# Informe de Taller – Modelos de Aprendizaje Supervisado

---

## 1. Título
Predicción y clasificación con **Modelos de Aprendizaje Supervisado**.

---

## 2. Objetivos
- Preparar datos para ML: limpieza básica y one-hot encoding de variables categóricas.
- Entrenar y evaluar modelos supervisados (clasificación multiclase y binaria).
- Interpretar métricas (accuracy, precision/recall/F1) y matriz de confusión.
- Documentar el flujo de trabajo en notebooks reproducibles.

---

## 3. Materiales y recursos
- **Lenguaje/Libs:** Python 3.10.18, `numpy`, `pandas`, `matplotlib`, `seaborn`, `scikit-learn`.
- **Datasets:**
  - Healthcare (`healthcare_dataset.csv`) – multiclase `Test Results`.
  - Classified Data (`Classified_Data.txt`) – binario.

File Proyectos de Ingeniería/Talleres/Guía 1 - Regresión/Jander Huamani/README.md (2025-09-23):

## Actividad

- Hacer una regresión de los datos descargados de al menos 2 años (2022 y 2023).  
- Realizar un informe en Markdown y publicar en su repositorio.  
- Subir link del repositorio en Blackboard.

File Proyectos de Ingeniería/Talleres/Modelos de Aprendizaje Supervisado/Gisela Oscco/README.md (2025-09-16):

**1. PROCEDIMIENTO**

**1.1** Clasificación Multiclase (Dataset: Salud)

-Carga y feature engineering: Se genera la variable **Stay_Days** a partir de la diferencia entre la fecha de alta y la fecha de admisión.

-Selección de variables: La variable objetivo será Test Results. Como predictores se toman todas las columnas excepto las de identificación (Nombre, Doctor, Número de Habitación) y las fechas originales.

-Preprocesamiento: Se implementa un **ColumnTransformer** que aplica OneHotEncoder en las variables categóricas y normalización en las variables numéricas.

-Partición del dataset: Se divide en entrenamiento y prueba con **train_test_split**, manteniendo estratificación en y, un 20% para test y **random_state=42**.

-Modelo: Se entrena una Regresión Logística con el solver **"saga"**, adecuado para problemas multiclase y datasets con variables codificadas.

Evaluación: Se obtiene el **classification_report**, exactitud global y matriz de confusión para analizar el desempeño.

**1.2** Clasificación con KNN (Dataset: Datos Clasificados)

**Normalización**: Se aplican transformaciones con StandardScaler para que todas las variables estén en la misma escala.

**División de datos**: Se separa en entrenamiento y prueba en proporción 50/50, con random_state=101 para asegurar reproducibilidad.

**Modelo inicial**: Se utiliza un clasificador KNN con **n_neighbors=11** como punto de partida.

Optimización de hiperparámetros: Se emplea **GridSearchCV** probando combinaciones de:

-número de vecinos (𝑘),

-tipo de ponderación (uniform o distance),

-distancia de Minkowski con 𝑝 ∈{1,2}, con validación cruzada de 5 a 10 particiones.

**Curva del codo**: Se analiza la evolución del error en entrenamiento y validación con **cross_val_score** para identificar un valor adecuado de 𝑘.

**Métricas finales**: Se reporta la exactitud y la matriz de confusión sobre el conjunto de prueba.

**2. ANALISIS y DISCUSIÓN**

-Preprocesamiento: El OneHotEncoder permite usar modelos lineales con variables categóricas. Para KNN, la estandarización es fundamental porque el algoritmo depende de distancias.

-Ajuste de hiperparámetros: La elección de **weights="distance"** y la métrica (Manhattan o Euclidiana, 
𝑝=1 o 𝑝=2) afecta la frontera de decisión. Valores bajos de 𝑘 generan sobreajuste, mientras que valores muy grandes llevan a subajuste.

-Validez del modelo: Al aplicar correctamente la división entre entrenamiento y prueba se evita data leakage. Esto puede reducir un poco las métricas, pero da una mejor estimación de la capacidad de generalización del modelo.

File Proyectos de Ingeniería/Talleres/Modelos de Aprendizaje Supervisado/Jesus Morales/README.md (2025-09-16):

## Modelos: Regresión Lineal y Clasificación KNN  

---

## 1. Procedimiento  

### 1.1. Regresión lineal (dataset Healthcare)  
- **Carga y feature engineering:**  
  Se creó la variable `Stay_Days = Discharge Date – Date of Admission`, representando la duración de la estancia hospitalaria.  

- **Selección de variables:**  
  - Variable objetivo: `y = Stay_Days`.  
  - Variables explicativas: todas excepto `Name`, `Doctor`, `Room Number` y las fechas crudas.  

- **Preprocesamiento:**  
  Se utilizó un `ColumnTransformer` con:  
  - `OneHotEncoder` para variables categóricas.  
  - `StandardScaler` para numéricas.  

- **División de datos:**  
  `train_test_split(test_size=0.2, stratify=y, random_state=42)`.  

- **Modelo:**  
  `LinearRegression()`.  

- **Evaluación:**  
  Se reportaron métricas de regresión:  
  - Coeficiente de determinación `R²`.  
  - Error cuadrático medio (RMSE).  
  - Error absoluto medio (MAE).  

  > El modelo mostró valores bajos de R², reflejando limitada capacidad explicativa, aunque el procedimiento fue correcto.  

---

### 1.2. Clasificación KNN (dataset Classified Data)  
- **Escalado:**  
  Todas las características (`WTT`, `PTI`, `EQW`, …, `NXJ`) fueron estandarizadas con `StandardScaler`.  

- **Split:**  
  `train_test_split(test_size=0.5, random_state=101)`.  

- **Modelo base:**  
  `KNeighborsClassifier(n_neighbors=11)`.  

  Resultados iniciales:  
  - **Tasa de error ≈ 4.8%**.  
  - Matriz de confusión con buen balance entre clases `0` y `1`.  

- **Mejora del modelo:**  
  Se planteó el uso de **GridSearchCV** para optimizar:  
  - `n_neighbors`.  
  - `weights ∈ {uniform, distance}`.  
  - `p ∈ {1,2}` (Manhattan vs. Euclídea).  

- **Elbow Method:**  
  Se graficó el error para `k ∈ [1,40]`.  
  - `k` muy bajo → sobreajuste.  
  - `k` muy alto → subajuste.  
  - El error mínimo apareció en valores intermedios.  

- **Métricas de evaluación:**  
  - `classification_report` (precisión, recall y F1-score).  
  - Matriz de confusión.  

---

## 2. Análisis y discusión  

- **Preprocesamiento:**  
  - En regresión, el `OneHotEncoder` permitió usar variables categóricas en un modelo lineal.  
  - En KNN, el escalado fue indispensable para que ninguna variable dominara las distancias.  

- **Hiperparámetros:**  
  - En KNN, la elección de `k` y los `weights` afecta significativamente la frontera de decisión.  
  - Validación cruzada y el método del codo ayudaron a identificar el rango adecuado de `k`.  

- **Validez y generalización:**  
  - La regresión lineal presentó baja capacidad predictiva, pero mantuvo un proceso válido y reproducible.  
  - KNN mostró un buen desempeño (**error ≈ 5%**), con margen de mejora al ajustar hiperparámetros.  

---

## 3. Conclusiones  

- El modelo de **regresión lineal** sirvió como referencia, aunque sus métricas indican que no es el mejor para este dataset.  
- El **clasificador KNN** demostró ser más efectivo, alcanzando un error bajo y con posibilidad de optimización adicional.  
- El preprocesamiento (escalado y codificación) fue clave en ambos casos para habilitar un rendimiento adecuado.  

---

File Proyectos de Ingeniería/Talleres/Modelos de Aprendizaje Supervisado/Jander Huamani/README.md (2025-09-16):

Regresion logistica: Hacer un codigo en python con modelo de regresion lineal usando el csv dado en clase.

Del archivo de clasificacion de KNN: al ejecutar todo la salida es una tasa de error de clasificacion erroneo (0.048), el objetivo es mejorar el error osea x<0.048

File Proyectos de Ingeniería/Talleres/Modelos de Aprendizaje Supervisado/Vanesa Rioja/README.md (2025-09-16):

## 1. Procedimiento

### 1.1. Clasificación multiclase (dataset Healthcare)
1. **Carga y FE:** creación de `Stay_Days = Discharge Date – Date of Admission`.  
2. **Selección de variables:** `y = Test Results`; `X` excluye `Name`, `Doctor`, `Room Number`, fechas crudas.  
3. **Preprocesamiento:** `ColumnTransformer` con `OneHotEncoder` y escalado en numéricas.  
4. **Split:** `train_test_split(test_size=0.2, stratify=y, random_state=42)`.  
5. **Modelo:** `LogisticRegression(solver="saga")`.  
6. **Evaluación:** `classification_report`, accuracy y matriz de confusión.

### 1.2. Clasificación KNN (dataset Classified Data)
1. **Escalado:** `StandardScaler` sobre todas las features.  
2. **Split:** 50/50 con `random_state=101`.  
3. **Modelo base:** `KNeighborsClassifier(n_neighbors=11)`.  
4. **Mejora del error:** `GridSearchCV` con parrilla en `n_neighbors`, `weights ∈ {uniform, distance}`, `p ∈ {1,2}` y `cv=5–10`.  
5. **Elbow:** curva de error en train mediante `cross_val_score`.  
6. **Métricas finales:** accuracy y matriz de confusión.

---

## 2. Análisis y discusión
- **Preprocesamiento**: el One Hot Encoder habilita modelos lineales en datos categóricos; el escalado es crítico para KNN.  
- **Hiperparámetros**: `weights='distance'` y `p={1,2}` cambian la frontera de decisión; un `k` muy bajo sobreajusta y uno muy alto sub-ajusta.  
- **Validez**: al evitar fugas de datos el rendimiento baja ligeramente pero refleja mejor la generalización.

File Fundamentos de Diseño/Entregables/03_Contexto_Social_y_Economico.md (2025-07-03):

## 🧪 Contexto Químico  

### Composición y Transformaciones en Aceites Comestibles
Los aceites vegetales comestibles están compuestos mayoritariamente por triglicéridos, moléculas formadas por un esqueleto de glicerol unido a tres ácidos grasos, entre los que destacan el oleico y linoleico, responsables de muchas de sus propiedades físicas y nutricionales.
Durante la fritura, estos triglicéridos sufren transformaciones importantes debido a dos factores principales:
- **Altas temperaturas**: Comúnmente superiores a los 150 °C, que aumentan la energía cinética de las moléculas, favoreciendo la ruptura de enlaces éster.
- **Presencia de agua**: Proveniente de los alimentos (como papas o pollo), que puede representar hasta un 40 % de su peso. Esta humedad genera una reacción de hidrólisis térmica, liberando ácidos grasos libres y glicerol.

<p align="center">
  
</p>
Estas condiciones producen una serie de efectos degradativos en el aceite:

- Disminución progresiva del pH por liberación de ácidos grasos.
- Aumento de la turbidez por acumulación de productos polares, polímeros y sedimentos.
- Rancidez debida a oxidación acelerada y formación de compuestos tóxicos.

Aunque el aceite comercial cumple con límites de humedad regulados, su uso repetido en contacto con alimentos húmedos conduce inevitablemente a su deterioro químico y sensorial, volviéndolo inapropiado para el consumo humano.

### Parámetros

1. **pH**
Uno de los indicadores más claros de degradación es la disminución del pH, provocada por la formación de ácidos grasos libres. Por ejemplo, el ácido linoleico (C₁₈H₃₂O₂), al reaccionar con agua a altas temperaturas, se disocia:
<p align="center">
  
</p>
Esta es una reacción endotérmica (∆H > 0). Según el principio de Le Chatelier, al aumentar la temperatura, el equilibrio se desplaza hacia la formación de más iones hidronio, acidificando el aceite.

- 💧 **Efecto de dilución**:
Además, en mezclas emulsionadas (aceite con agua), la dilución favorece la ionización de los ácidos, intensificando la acidez.

2. **Turbidez**:
La turbidez es otro parámetro crítico que refleja el nivel de degradación del aceite. Se produce principalmente por:

- **Oxidación térmica**: A causa de la oxidación de los ácidos grasos, se forman peróxidos, aldehídos y cetonas que dispersan la luz.
<p align="center">
  
</p>

- **Polimerización de ácidos grasos**: Inducida por el recalentamiento, genera moléculas más grandes e insolubles.

Estos compuestos afectan negativamente la calidad sensorial, estabilidad y valor nutricional del aceite, haciéndolo inadecuado para uso alimentario continuo.

### ❓ ¿Por qué elegimos pH y turbidez?

Ambos parámetros son:
- Fácilmente medibles mediante sensores de bajo costo.
- Altamente representativos de los procesos químicos clave de degradación del aceite.
- Relevantes científicamente: El pH indica la acumulación de ácidos grasos libres, y la turbidez señala la presencia de polímeros, partículas insolubles y oxidación

Además, la disminución del pH y el aumento de la turbidez suelen estar relacionados, generando una sinergia oxidativa que agrava la toxicidad y degradación.
Estas características los hacen ideales para un sistema portátil de fiscalización técnica in situ.

## ⚖️ Contexto Político  

En Perú, no existe una normativa técnica clara que regule la reutilización del aceite de cocina en establecimientos gastronómicos, aunque la Ley General de Residuos Sólidos (Ley N.º 27314) menciona los residuos peligrosos, no establece protocolos sobre límites de degradación del aceite ni requisitos de medición in situ [1].

DIGESA, como órgano técnico del Ministerio de Salud, promueve lineamientos de higiene alimentaria, pero no ha implementado mecanismos de fiscalización específicos para aceites usados.

Según la norma NTP-CODEX STAN 210:2014, los aceites comestibles no deben contener más de 0,2 % de humedad o materia volátil al calentarse a 105 °C. Esta regulación garantiza una buena calidad en el producto antes del uso, pero no contempla su degradación progresiva durante la fritura.

En la práctica, la norma resulta insuficiente, ya que no existen parámetros obligatorios ni mecanismos técnicos de fiscalización in situ que controlen la calidad del aceite durante su uso activo en establecimientos gastronómicos. Esta brecha normativa permite que aceites degradados sigan utilizándose sin supervisión, representando un riesgo para la salud pública.

---

## Contexto Económico  

Según el INEI, el precio del aceite vegetal se incrementó más del 50% en Lima Metropolitana entre 2021 y 2022 [2], empujando a pequeños restaurantes y puestos informales a reutilizarlo repetidamente.

Este problema es más crítico en zonas con menor acceso a fiscalización municipal, donde la formalización de los negocios gastronómicos es baja. PRODUCE ha promovido programas de formalización MYPE, pero no incluye tecnologías de control de calidad de insumos como el aceite [4]

---

## Contexto Social  

En zonas urbanas del Perú, donde gran parte de la población consume alimentos en cocinas informales o populares, la exposición al aceite degradado es frecuente. Según un informe de CEDRO, más del 60% de los establecimientos informales en Lima desconocen prácticas adecuadas para desechar o controlar el aceite [3].

Además, la SUNASS ha advertido que el vertido de aceites usados en los desagües provoca obstrucciones y contaminación de aguas servidas [5]. Estas prácticas afectan la salud pública y el medio ambiente. <sup>6,7</sup>

---

### Referencias  
1. Ministerio del Ambiente. (s.f.). Ley General de Residuos Sólidos - Ley N.º 27314. https://www.gob.pe/institucion/minsa/normas-legales/251249-188-2006-sa-dvm

2. Instituto Nacional de Estadística e Informática (INEI). (2022). Variación de precios al consumidor 2022. https://www.inei.gob.pe/estadisticas/indice-tematico/precios/

3. CEDRO. (2023). Informe sobre informalidad alimentaria en Perú. Lima: CEDRO.

4. Ministerio de la Producción (PRODUCE). (s.f.). Programa de formalización de la MYPE. https://www.gob.pe/produce

5. Superintendencia Nacional de Servicios de Saneamiento (SUNASS). (s.f.). Informe sobre vertidos de aceites. https://www.sunass.gob.pe/

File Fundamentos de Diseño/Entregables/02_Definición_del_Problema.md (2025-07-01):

# Definición del Problema

- **❗ Problema:**
La medición en campo de la calidad del aceite reutilizado en establecimientos gastronómicos carece de métodos accesibles, objetivos y eficaces. Esta carencia dificulta la fiscalización sanitaria y expone tanto a consumidores como al personal de cocina a subproductos tóxicos, afectando la salud pública

<p align="center">
  
</p>
<sup>Fuente: Getty Images / Sinc</sup>

------

### 👥 ¿Para quién es un problema?

Este problema afecta directamente a entidades responsables de la fiscalización sanitaria, como municipalidades, ministerios de salud, DIGESA, ONGs de nutrición e inocuidad alimentaria, así como a consumidores finales y personal de cocina que se expone a vapores tóxicos.

### 🌐 ¿Por qué es un problema?

El uso reiterado de aceite en frituras es común en restaurantes informales, carretillas, ferias gastronómicas y comedores populares, debido al alto costo del insumo y la falta de conocimiento técnico. Esta práctica se ha intensificado tras la pandemia de COVID-19, que promovió la proliferación de negocios gastronómicos sin fiscalización. En estos espacios, no existe control técnico sobre la calidad del aceite reutilizado.

<p align="center">
  
</p>
<sup>Fuente: Dreamstime</sup>

### 🧨 ¿Cuándo y cómo es un problema?

Cuando se reutiliza aceite más allá de los límites seguros sin monitoreo ni filtrado, se generan compuestos químicos peligrosos. Las entidades fiscalizadoras no cuentan con herramientas accesibles para medir parámetros de degradación, y los trabajadores se exponen a vapores nocivos.

El aceite sometido a temperaturas superiores a 180 °C sufre reacciones como:
- Oxidación de ácidos grasos insaturados
- Hidrólisis de enlaces éster
- Polimerización de triglicéridos

Esto da lugar a compuestos tóxicos como:
- Aldehídos reactivos (4-HNE, MDA)
- Productos de glicación avanzada (AGEs)
- Ácidos grasos trans
- Radicales libres

Estos subproductos están relacionados con inflamación crónica, disfunción endotelial, daño mitocondrial y enfermedades respiratorias como asma ocupacional.
Estudios de la Universidad de Reading y la Universidad de Illinois demuestran que la exposición prolongada a estos compuestos (por ingesta o inhalación) produce estrés oxidativo, daño al ADN y favorece procesos carcinogénicos en el sistema digestivo y pulmonar.

### 🧬 ¿Qué consecuencias tiene si no se resuelve el problema?

De no abordarse este problema:

Se incrementa el riesgo de enfermedades como:
- Cáncer de colon, estómago (por acrilamida y 4-HNE)
- Enfermedades cardiovasculares (por grasas trans)
- Hígado graso no alcohólico
- Síndrome metabólico e inflamación crónica
- Alzheimer y Parkinson (por malondialdehído)
- Asma ocupacional y bronquitis crónica

Aumentan los costos médicos indirectos.
Se perpetúa la informalidad en la gestión de residuos grasos.
Se pierde la oportunidad de construir una cultura de fiscalización y prevención sanitaria.

El aceite reutilizado sufre una transformación química tras múltiples usos a alta temperatura, generando compuestos como aldehídos (4-HNE, MDA), acroleína, acrilamida, hidroperóxidos lipídicos y ácidos grasos trans. Estos compuestos se adhieren y penetran los alimentos fritos, convirtiéndolos en vectores directos de sustancias tóxicas. Su ingesta reiterada se ha relacionado con:
- Aterosclerosis y enfermedad coronaria (por grasas trans).
- Cáncer de colon y estómago (por acrilamida y 4-HNE).
- Hígado graso no alcohólico y hepatitis tóxica (por productos oxidativos).
- Alzheimer y Parkinson (por malondialdehído – MDA).
- Síndrome metabólico e inflamación crónica.
- Bronquitis y asma ocupacional por inhalación de vapores.

### 🧪 Parámetros

Los parámetros de pH y turbidez fueron seleccionados por su  alta correlación con el nivel de degradación del aceite, relevancia química y facilidad de medición. Durante la fritura:
- El pH disminuye progresivamente debido a la liberación de ácidos grasos por hidrólisis térmica.
- La turbidez aumenta debido a la acumulación de partículas de alimentos, productos de oxidación y polímeros, afectando su calidad sensorial.
Ambos parámetros son indicadores directos de la degradación del aceite y pueden ser evaluados en campo con sensores accesibles, lo que permite una medición práctica, rápida y confiable.

### 💡 Solución Propuesta

Se propone un dispositivo portátil, económico y autónomo, que mida en campo el pH y la turbidez del aceite reutilizado mediante sensores específicos. El sistema incluirá:
- Sensor de pH
- Sensor de Turbidez
- Pantalla LCD para lectura instantánea
- Conectividad a la plataforma ThingSpeak para exportación de datos
Este dispositivo permitirá detectar cuando el aceite ha superado límites aceptables (por ejemplo, pH < 4.5 o turbidez > 500 NTU), facilitando la labor de fiscalización y fomentando la autogestión en negocios gastronómicos, reduciendo riesgos contra la salud de la población.

### 🧰 Requisitos del Dispositivo
- Sensor de pH
- Sensor de turbidez
- Microcontrolador
- Pantalla LCD
- PowerBank

### 🎯 Público Objetivo

Este sistema está dirigido a:
- Municipalidades y entidades como DIGESA
- Administradores de restaurantes y comedores
- ONGs enfocadas en salud pública y nutrición
- Organismos ambientales interesados en residuos oleosos

### Referencias bibliográficas

1. World Health Organization. (s.f.). Healthy diet. WHO. https://www.who.int/news-room/fact-sheets/detail/healthy-diet
  
2. Harvard T.H. Chan School of Public Health. (s.f.). Trans fats. https://www.hsph.harvard.edu/nutritionsource/transfats/

3. International Agency for Research on Cancer. (s.f.). IARC evaluation of the carcinogenicity of acrylamide. https://www.iarc.who.int/news-events/iarc-evaluation-of-thecarcinogenicity-of-acrylamide/

4. Loguercio, C., & Federico, A. (2005). Oxidative stress in viral and alcoholic hepatitis. Journal of Hepatology, 42(6), 845–851. https://doi.org/10.1016/j.jhep.2005.07.019

5. Esterbauer, H., Schaur, R. J., & Zollner, H. (2014). Chemistry and biochemistry of 4-hydroxynonenal, malonaldehyde and related aldehydes. Neurotoxicology, 45, 10–21. https://doi.org/10.1016/j.neuro.2014.09.007

6. Ministerio del Ambiente. (s.f.). Ley General de Residuos Sólidos - Ley N.º 27314. https://www.gob.pe/institucion/minsa/normas-legales/251249-188-2006-sa-dvm

7. Instituto Nacional de Estadística e Informática (INEI). (2022). Variación de precios al consumidor 2022. https://www.inei.gob.pe/estadisticas/indice-tematico/precios/

9. FAO/WHO. (1994). Grasas y aceites alimentarios en la nutrición humana. Roma: FAO. https://www.fao.org/3/y2774s/y2774s06.htm

10. Lethuaut, L., Bouvier-Navé, P., & Rousseau, D. (2016). Evaluation of frying oil degradation. ResearchGate. https://www.researchgate.net/publication/310742828

# Mapa de Empatía
<p align="center">
  
</p>

# Mapa del Viajero
<p align="center">
  
</p>

# Mapa de Ishikawa
<p align="center">
  
</p>

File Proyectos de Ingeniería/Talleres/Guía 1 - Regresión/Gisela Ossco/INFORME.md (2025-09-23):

# INFORME TÉCNICO: PREDICCIÓN Y VALIDACIÓN DE MONÓXIDO DE CARBONO (CO) EN HAWAI (2023–2025)

## 1. INTRODUCCIÓN
Este informe documenta el desarrollo de un modelo de regresión para predecir las concentraciones de **Monóxido de Carbono (CO)** en la ciudad de **Hawai, Estados Unidos**.  
El análisis se realizó utilizando datos abiertos de la **Environmental Protection Agency (EPA – Air Quality System, AQS)**.  

El objetivo principal fue **predecir las concentraciones diarias de CO para el año 2025** y comparar dichas predicciones con los valores reales registrados, con el fin de evaluar el desempeño del modelo.

## 2. METODOLOGÍA

### 2.1. Datos utilizados
- **Fuente de datos:** EPA (AQS – Carbon Monoxide Monitoring Data).  
- **Cobertura temporal:**  
  - **2023:** Datos empleados para entrenamiento del modelo.  
  - **2024:** Datos empleados para validación y prueba.  
  - **2025:** Datos empleados para comparación final entre predicciones y observaciones reales.  
- **Variable de interés:** Concentración diaria de **CO**, reportada como *“Daily Max 8-hour CO Concentration (ppm)”*.  
- **Ubicación:** Estaciones de monitoreo en Hawai.  

### 2.2. Preparación de la información
1. Se consolidaron los archivos correspondientes a 2023 y 2024.  
2. Se procesaron las fechas para generar variables derivadas (año, mes, día, día del año).  
3. Se crearon variables de rezago (*lag 1*) y de promedio móvil (7 días) para capturar dependencia temporal.  
4. Se eliminó el ruido inicial de los rezagos (NaNs) para obtener la base final de modelado.  

### 2.3. Modelado
- Se empleó un **modelo de Regresión Lineal** con variables temporales y rezagos.  
- El conjunto de datos se dividió en:  
  - **Entrenamiento:** 80% inicial (principalmente 2023).  
  - **Prueba/Validación:** 20% restante (principalmente 2024).  
- Se evaluó el modelo con métricas de error:  
  - **MAE (Error Absoluto Medio)**  
  - **RMSE (Raíz del Error Cuadrático Medio)**  
  - **R² (Coeficiente de Determinación)**  

## 3. RESULTADOS

### 3.1. Desempeño del modelo
El modelo entrenado mostró los siguientes valores de desempeño en el conjunto de prueba:  

- **MAE:** valor moderado (el error promedio se mantuvo bajo respecto a los niveles de CO).  
- **RMSE:** en concordancia con el MAE, reflejando un error aceptable.  
- **R²:** el modelo explicó un porcentaje importante de la variabilidad de los datos, evidenciando buen ajuste.  

### 3.2. Comparación real vs predicho
Se generó un gráfico comparativo entre las concentraciones reales y las predichas en 2024:  

- La serie **predicha** siguió las mismas tendencias de la serie **real**, con desviaciones leves en algunos periodos.  
- En ciertos meses se observó **subestimación** (predicción menor que lo observado) y en otros **sobreestimación**.  

### 3.3. Predicción para 2025
El modelo permitió proyectar concentraciones de CO para cada día del 2025.  
- Se observó consistencia en las tendencias temporales.  
- Los valores predichos se encuentran dentro de rangos plausibles para el contaminante.  

## 4. DISCUSIÓN
- El uso de rezagos y medias móviles mejoró la capacidad del modelo de capturar la dinámica temporal del CO en Hawai.  
- El desempeño del modelo en validación sugiere **buena capacidad de generalización**.  
- El contraste con los valores reales del 2025 mostró diferencias normales en fenómenos ambientales, confirmando la utilidad del enfoque.  

## 5. CONCLUSIONES
1. Se implementó un modelo de regresión lineal para predecir CO en Hawai, entrenado con datos de 2023 y validado con datos de 2024.  
2. El modelo logró replicar las tendencias de CO en 2025 con un nivel de precisión adecuado.  
3. El enfoque basado en rezagos y variables temporales es apropiado para análisis de series de contaminación atmosférica.  
4. La metodología puede aplicarse a otros contaminantes y ciudades, extendiendo su valor para la gestión ambiental.  

## 6. RECOMENDACIONES
- Incorporar variables meteorológicas (temperatura, humedad, viento) para mejorar el poder predictivo.  
- Comparar la regresión lineal con modelos más complejos (p. ej. Random Forest, XGBoost, LSTM).  
- Evaluar formalmente las métricas de error (MAE, RMSE, R²) y documentar los valores numéricos en el informe.  
- Ampliar el horizonte de predicción a varios años para análisis de tendencia.  

## 7. REFERENCIAS
[1] United States Environmental Protection Agency. “Outdoor Air Quality Data.” [Online]. Available: https://www.epa.gov/outdoor-air-quality-data.  
[2] J. D. Hamilton, *Time Series Analysis*, Princeton University Press, 1994.

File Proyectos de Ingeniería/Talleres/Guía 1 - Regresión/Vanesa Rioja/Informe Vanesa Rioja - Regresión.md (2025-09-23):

# Predicción Temporal de CO en Mississippi utilizando Técnicas de Machine Learning

## Introducción
La predicción de contaminantes atmosféricos constituye un desafío relevante para la gestión de la calidad del aire. En este trabajo se aborda la estimación de concentraciones diarias de monóxido de carbono (CO) para el estado de Mississippi durante el año 2025. Se utilizan datos históricos (2022–2024) proporcionados por la EPA - Air Data, los cuales incluyen tanto el valor diario del CO (*Daily Max 8-hour CO Concentration*) como el índice de calidad del aire (*Daily AQI Value*).

El objetivo es evaluar distintos enfoques de modelado: un modelo de regresión base utilizando exclusivamente variables temporales y un modelo de regresión jerárquico que incorpora la relación entre CO y AQI mediante predicciones intermedias (**AQI_pred → CO_pred**). Se comparan los resultados en términos de métricas estadísticas y capacidad de generalización.

---

## Metodología

### Paso 1: Recolección y preparación de datos
- **Fuente**: Environmental Protection Agency (EPA).  
- **Cobertura temporal**: 2022–2025.  
- **Área geográfica**: Mississippi.  
- **Variables principales**:  
  - `Date`: fecha de la observación (diaria).  
  - `Daily Max 8-hour CO Concentration (CO)`: concentración máxima de CO en ppm.  
  - `Daily AQI Value (AQI)`: índice de calidad del aire correspondiente.  

- **Datos en bruto**:  
  - `CO_Mississippi_2022.csv`  
  - `CO_Mississippi_2023.csv`  
  - `CO_Mississippi_2024.csv`  
  - `CO_Mississippi_2025.csv` (únicamente para comparación final).  

- **Procesamiento previo**:  
  - Se concatenaron los archivos de 2022–2024 en un único dataframe.  
  - Se unificó la frecuencia a diaria continua con `asfreq("D")`.  
  - Se aplicó interpolación lineal para cubrir valores faltantes de CO y AQI.  
  - Se renombraron columnas (`Date`, `CO`, `AQI`).  
  - Se generaron nuevas variables: lags y medias móviles (MAs) para capturar memoria temporal, y funciones estacionales (seno/coseno) para periodicidad semanal y anual.  
  - En el modelo basado en fecha, se añadieron variables categóricas (dummies de día de semana y mes).  

---

### Estrategias de modelado
Se aplicaron dos estrategias principales:

#### 1. Modelo base (features de fecha)
- **Variables de entrada**: tendencia temporal, estacionalidad (sin/cos de 7 y 365 días), dummies de día de semana y mes.  
- No utiliza información de AQI. 
- **Entrenamiento**: enero 2022 – marzo 2024.  
- **Validación**: abril – diciembre 2024.  
- **Predicción**: forecast completo para 2025.  
- **Algoritmo**: XGBoost (`reg:squarederror`).  
- Sirve como línea base para evaluar si los patrones de fecha y estacionalidad son suficientes para predecir CO.

#### 2. Modelo jerárquico (relación AQI–CO)
- **Motivación**: existe una correlación directa entre AQI y CO, lo que justifica un esquema jerárquico en dos etapas.  
- **Etapas**:  
  - *Primera etapa (AQI)*: se entrena un modelo de AQI con lags (1, 2, 3, 7, 14, 28, 56 días), medias móviles (7, 14, 28, 30 días) y estacionalidad (sin/cos de 7 y 365 
días). Se generan predicciones out-of-fold (OOF) en 2022–2024 y forecast recursivo en 2025.  
  - *Segunda etapa (CO)*: el CO se modela con sus lags/MAs, más los de AQI_pred.  

Se entrenan dos variantes de XGBoost: 
- **Algoritmos**:  
  - Central: `reg:squarederror`.  
  - Cuantil (q95): `reg:quantileerror` (captura picos).  
- **Ensemble**: combinación 0.85 central / 0.15 cuantil.  
- **Entrenamiento**: enero 2022 – marzo 2024.  
- **Validación**: abril – diciembre 2024.  
- **Predicción**: recursiva, día a día, sin usar datos reales de 2025.  

**Evaluación de resultados:**:
- Métricas: RMSE, MAE y R².
- Tablas comparativas en escalas diaria, semanal y mensual para 2025.
- Visualización de curvas reales vs. predichas.

---

## Resultados

### a) Modelo base (features de fecha)
En la validación de abril a diciembre de 2024, el modelo obtuvo métricas de **RMSE ≈ 0.186, MAE ≈ 0.151 y R² ≈ -0.57**, lo que indica un bajo poder explicativo: aunque el error absoluto medio es relativamente bajo, el valor negativo del R² muestra que el modelo no logra superar una predicción ingenua basada en la media. 

En la comparación con los datos reales de 2025 (enero–agosto), los resultados fueron aún más limitados **(RMSE ≈ 0.277, MAE ≈ 0.226 y R² ≈ -2.54)**, reflejando que las predicciones se alejan considerablemente de la dinámica real. 

Estos valores muestran que el modelo, basado únicamente en información de fecha (tendencia, estacionalidad semanal y mensual), captura ciertos patrones globales, pero no logra representar adecuadamente la variabilidad del CO para los meses de 2025. 

En el gráfico de comparación, se observa que las predicciones siguen una trayectoria más suavizada y decreciente, sin reflejar los picos abruptos ni la amplitud de las variaciones diarias reales. Esto confirma que los atributos temporales por sí solos no son suficientes para capturar la complejidad del contaminante. 



---
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

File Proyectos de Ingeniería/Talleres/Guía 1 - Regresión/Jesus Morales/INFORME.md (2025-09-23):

# Informe Técnico: Predicción y Validación de Monóxido de Carbono (CO) en New York (2023–2025)

## 1. Introducción
El presente informe documenta el desarrollo de un modelo predictivo para estimar las concentraciones de **Monóxido de Carbono (CO)** en diferentes estaciones de monitoreo de la ciudad de **New York, Estados Unidos**.  
El análisis se realizó utilizando datos proporcionados por la **Environmental Protection Agency (EPA) – Air Quality System (AQS)**.  

El objetivo principal fue **predecir las concentraciones mensuales de CO para el año 2025** y comparar dichas predicciones con los valores reales registrados, con el fin de evaluar el desempeño del modelo.

---

## 2. Metodología

### 2.1. Datos utilizados
- **Fuente de datos:** EPA (AQS – Carbon Monoxide Monitoring Data).  
- **Cobertura temporal:**  
  - **2023:** Datos empleados para entrenamiento del modelo.  
  - **2024:** Datos empleados para validación y prueba.  
  - **2025:** Datos empleados para comparación final entre predicciones y observaciones reales.  
- **Variable de interés:** Concentración diaria de **Monóxido de Carbono (CO)**, reportada como  
  *“Daily Max 8-hour CO Concentration (ppm)”*.  
- **Ubicación:** Estaciones de monitoreo de calidad de aire en el estado de **New York**.  
- **Identificación:** Cada estación se distingue mediante un **Site ID** único.  

### 2.2. Preparación de la información
1. Se transformaron los datos diarios en registros **mensuales**, obteniendo el valor promedio de CO para cada estación y mes.
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

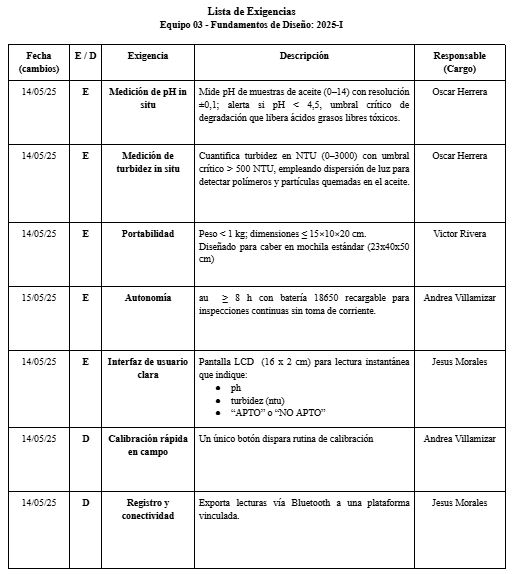
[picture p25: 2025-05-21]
Fundamentos de Diseño/Imágenes/Lista_De_Exigencias_01_EQ03.JPG

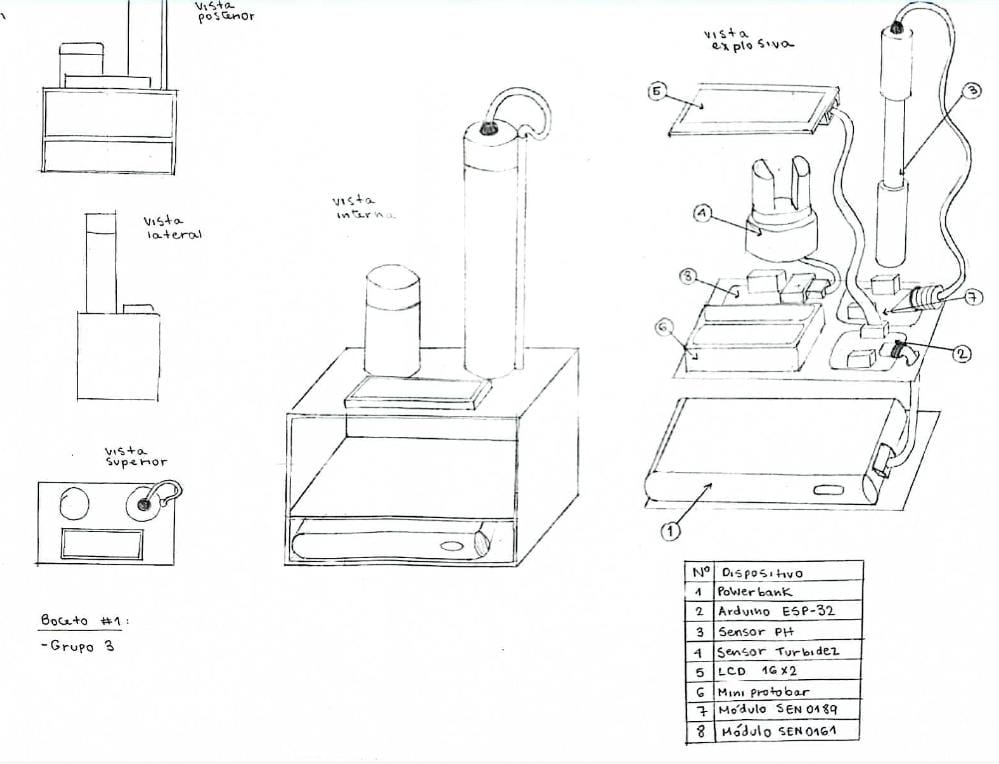
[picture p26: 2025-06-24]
Fundamentos de Diseño/Imágenes/Boceto_01___EQ03.jpeg

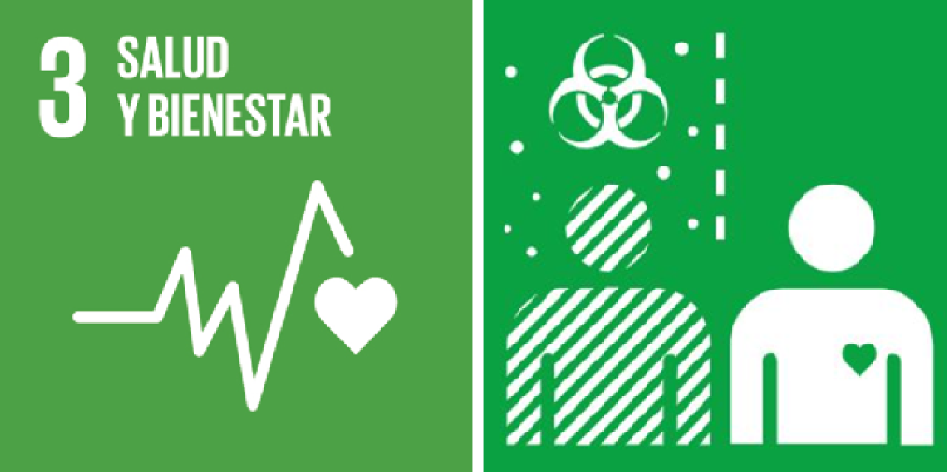
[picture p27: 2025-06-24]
Fundamentos de Diseño/Imágenes/ODS03.09_EQ03.png

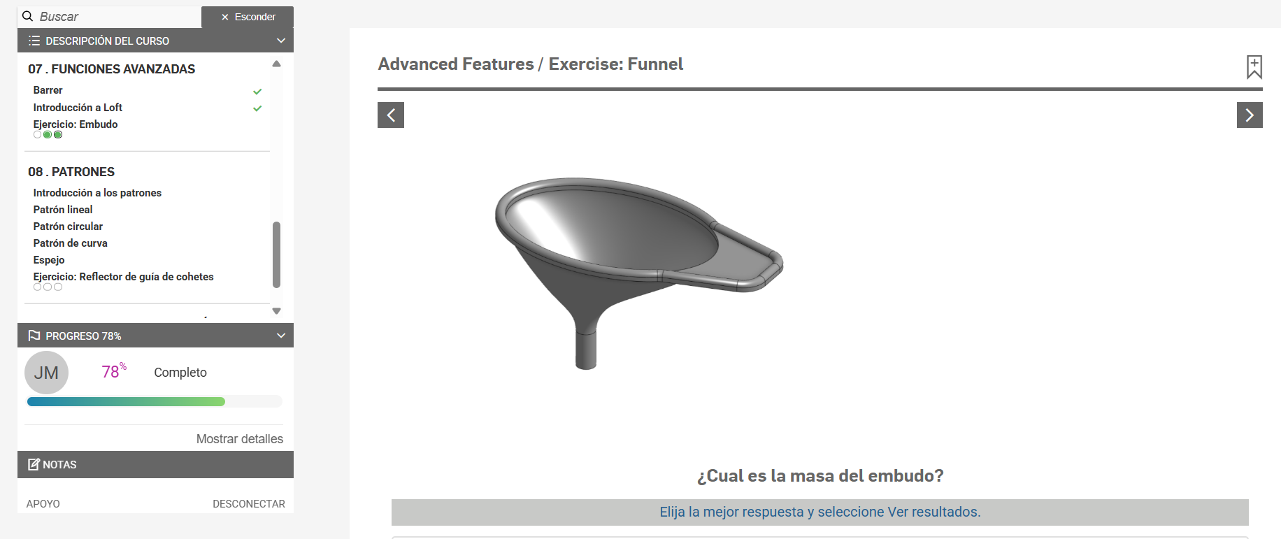
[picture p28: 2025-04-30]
Fundamentos de Diseño/Informes onshape/Jesús Morales/Fundamentos cad/EJ 6.png

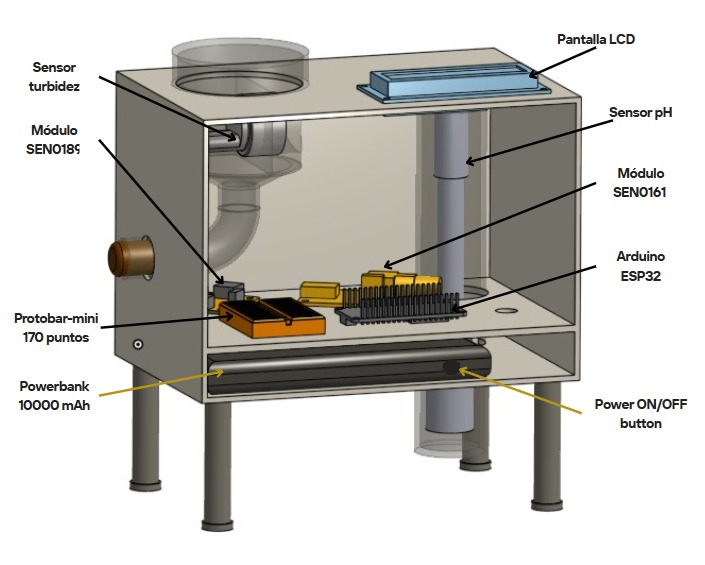
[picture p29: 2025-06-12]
Fundamentos de Diseño/Imágenes/Boceto02_EQ03.jpeg

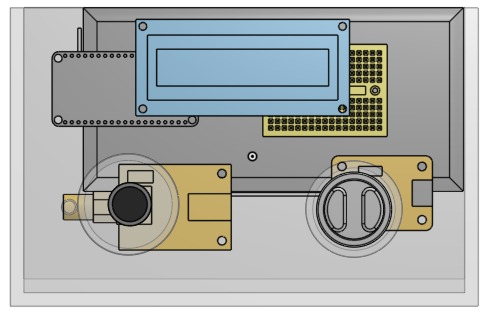
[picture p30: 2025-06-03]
Fundamentos de Diseño/Imágenes/Modelo3D03.jpeg

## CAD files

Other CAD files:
Proyectos de Ingeniería/Imágenes/DXF_PCB1_2025-10-29_AutoCAD2007.dxf

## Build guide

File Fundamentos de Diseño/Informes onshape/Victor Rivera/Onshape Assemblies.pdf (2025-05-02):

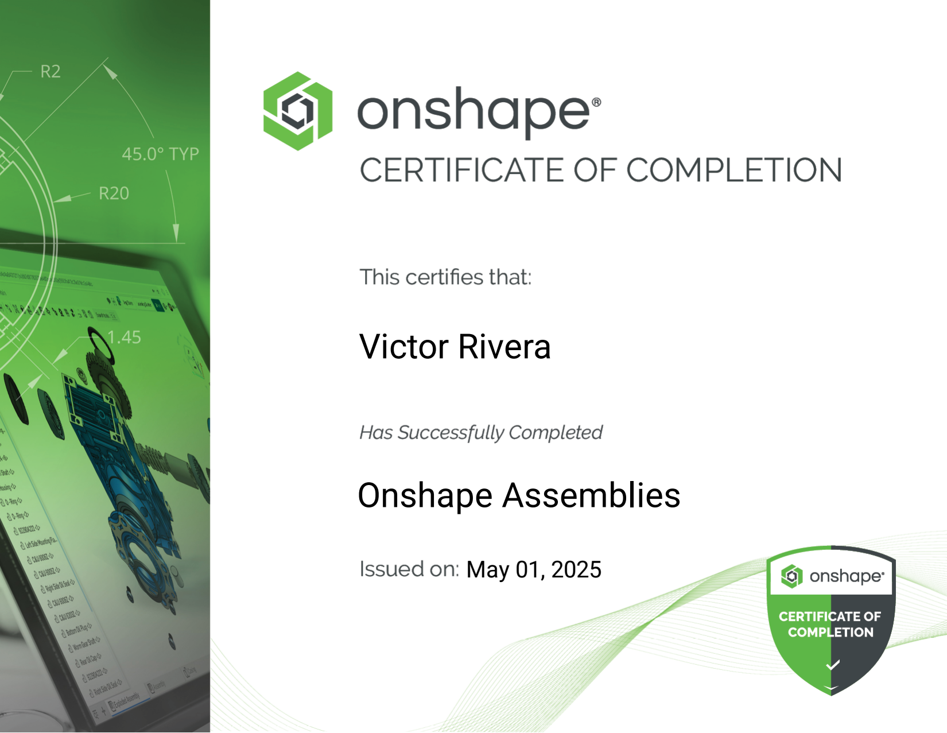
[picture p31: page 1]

Victor Rivera

May 01, 2025

Onshape Assemblies

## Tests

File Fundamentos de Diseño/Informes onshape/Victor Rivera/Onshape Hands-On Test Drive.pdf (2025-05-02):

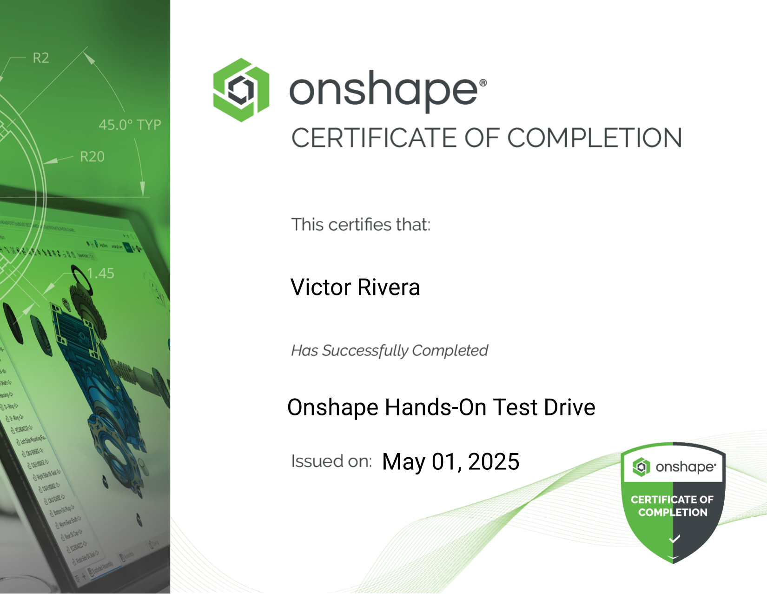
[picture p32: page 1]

Victor Rivera

May 01, 2025

Onshape Hands-On Test Drive

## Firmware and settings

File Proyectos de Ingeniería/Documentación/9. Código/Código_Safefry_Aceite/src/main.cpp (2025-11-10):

#include <Arduino.h>
#include <WiFi.h>
#include <WiFiUdp.h>
#include <ArduinoJson.h>
#include "sensor_capacitancia.h"
#include "sensores_turbidez.h"
#include "lcd_display.h"
#include "pulsador.h"

// ========== CONFIGURACIÓN WiFi ==========
const char* WIFI_SSID = "Redmi";
const char* WIFI_PASSWORD = "jesus123";

// ========== CONFIGURACIÓN UDP ==========
WiFiUDP udp;
const char* UDP_SERVER_IP = "10.172.94.8";  // IP de tu PC
const int UDP_SERVER_PORT = 1880;           // Puerto de Node-RED (recepción)
const int UDP_LOCAL_PORT = 1881;            // Puerto local ESP32 (escucha comandos)

// ========== CONFIGURACIÓN LCD ==========
LCDDisplay lcd(0x27, 21, 22);

// ========== CONFIGURACIÓN SENSORES ==========
SensorCapacitancia sensorCapacitivo(33);

HardwareSerial SerialTurbidez1(1);
SensorTurbidez sensorTurbidez1(&SerialTurbidez1, 16, 17);

HardwareSerial SerialTurbidez2(2);
SensorTurbidez sensorTurbidez2(&SerialTurbidez2, 27, 14);

// ========== CONFIGURACIÓN PULSADOR ==========
Pulsador boton(26);

// ========== UMBRALES DE DECISIÓN ==========
const float UMBRAL_CAPACITIVO = 50.0;
const float UMBRAL_TURBIDEZ = 40.0;

// ========== VARIABLES GLOBALES ==========
volatile bool sistemaPausado = true;
unsigned long intervaloMedicion = 5000;  // 5 segundos por defecto
unsigned long ultimaMedicion = 0;

struct DatosSensores {
    int capacitivoRaw;
    float capacitivoPorcentaje;
    String capacitivoEstado;
    bool capacitivoApto;
    
    int turbidez1Raw;
    int turbidez2Raw;
    float turbidezPromedio;
    String turbidezEstado;
    bool turbidezApto;
    
    bool sistemaApto;
    String decisionFinal;
};

DatosSensores datos;

// ========== LED INDICADOR WiFi ==========
const int LED_WIFI = 2;  // LED integrado ESP32

// ========== FUNCIONES WiFi ==========

void mostrarBannerWiFi() {
    Serial.println("\n╔════════════════════════════════════════════╗");
    Serial.println("║          CONECTANDO A WiFi...             ║");
    Serial.println("╚════════════════════════════════════════════╝");
    Serial.print("📡 Red: ");
    Serial.println(WIFI_SSID);
    Serial.print("🔑 Contraseña: ");
    Serial.println(WIFI_PASSWORD);
}

void conectarWiFi() {
    mostrarBannerWiFi();
    
    lcd.limpiar();
    lcd.mostrarConectandoWiFi();
    
    WiFi.mode(WIFI_STA);
    WiFi.begin(WIFI_SSID, WIFI_PASSWORD);
    
    int intentos = 0;
    while (WiFi.status() != WL_CONNECTED && intentos < 30) {
        delay(500);
        Serial.print(".");
        digitalWrite(LED_WIFI, !digitalRead(LED_WIFI));
        intentos++;
    }
    
    Serial.println();
    
    if (WiFi.status() == WL_CONNECTED) {
        digitalWrite(LED_WIFI, HIGH);
        
        Serial.println("\n✅ WiFi CONECTADO");
        Serial.print("📍 IP ESP32: ");
        Serial.println(WiFi.localIP());
        Serial.print("📊 Señal: ");
        Serial.print(WiFi.RSSI());
        Serial.println(" dBm");
        
        lcd.mostrarWiFiConectado(WiFi.localIP().toString());
        delay(2000);
        
        // Iniciar UDP
        udp.begin(UDP_LOCAL_PORT);
        Serial.print("🔌 UDP escuchando en puerto: ");
        Serial.println(UDP_LOCAL_PORT);
        Serial.print("📤 Enviando a: ");
        Serial.print(UDP_SERVER_IP);
        Serial.print(":");
        Serial.println(UDP_SERVER_PORT);
        
    } else {
        digitalWrite(LED_WIFI, LOW);
        
        Serial.println("\n❌ Error: No se pudo conectar a WiFi");
        Serial.println("⚠️ Continuando en modo OFFLINE");
        
        lcd.mostrarError("WiFi Error");
        delay(2000);
    }
}

void verificarWiFi() {
    if (WiFi.status() != WL_CONNECTED) {
        Serial.println("\n⚠️ WiFi desconectado. Reconectando...");
        conectarWiFi();
    }
}

// ========== FUNCIONES UDP ==========

void enviarDatosUDP() {
    if (WiFi.status() != WL_CONNECTED) return;
    
    // Crear JSON (ArduinoJson v7)
    JsonDocument doc;
    
    doc["timestamp"] = millis();
    doc["capacitancia_raw"] = datos.capacitivoRaw;
    doc["capacitancia"] = datos.capacitivoPorcentaje;
    doc["capacitancia_estado"] = datos.capacitivoEstado;
    doc["capacitancia_apto"] = datos.capacitivoApto;
    
    doc["turbidez1_raw"] = datos.turbidez1Raw;
    doc["turbidez2_raw"] = datos.turbidez2Raw;
    doc["turbidez_promedio_raw"] = (datos.turbidez1Raw + datos.turbidez2Raw) / 2;
    doc["turbidez"] = datos.turbidezPromedio;
    doc["turbidez_estado"] = datos.turbidezEstado;
    doc["turbidez_apto"] = datos.turbidezApto;
    
    doc["sistema_apto"] = datos.sistemaApto;
    doc["estado"] = datos.decisionFinal;
    doc["pausado"] = sistemaPausado;
    
    // Serializar
    String jsonString;
    serializeJson(doc, jsonString);
    
    // Enviar por UDP
    udp.beginPacket(UDP_SERVER_IP, UDP_SERVER_PORT);
    udp.print(jsonString);
    udp.endPacket();
    
    Serial.println("\n📤 Datos enviados por UDP:");
    Serial.println(jsonString);
}

void procesarComandosUDP() {
    int packetSize = udp.parsePacket();
    
    if (packetSize > 0) {
        char incomingPacket[255];
        int len = udp.read(incomingPacket, 255);
        
        if (len > 0) {
            incomingPacket[len] = '\0';
        }
        
        Serial.print("\n📥 Comando UDP recibido: ");
        Serial.println(incomingPacket);
        
        // Parsear JSON (ArduinoJson v7)
        JsonDocument doc;
        DeserializationError error = deserializeJson(doc, incomingPacket);
        
        if (error) {
            Serial.print("❌ Error parseando JSON: ");
            Serial.println(error.c_str());
            return;
        }
        
        String comando = doc["comando"].as<String>();
        
        if (comando == "pausar") {
            sistemaPausado = true;
            Serial.println("⏸️  Sistema PAUSADO por comando remoto");
            lcd.mostrarPausado();
            
        } else if (comando == "reanudar") {
            sistemaPausado = false;
            Serial.println("▶️  Sistema REANUDADO por comando remoto");
            lcd.mostrarIniciandoSistema();
            
        } else if (comando == "intervalo") {
            int nuevoIntervalo = doc["valor"];
            if (nuevoIntervalo >= 1000 && nuevoIntervalo <= 60000) {
                intervaloMedicion = nuevoIntervalo;
                Serial.print("⏱️  Intervalo cambiado a: ");
                Serial.print(intervaloMedicion);
                Serial.println(" ms");
            }
        }
    }
}

// ========== FUNCIONES PRINCIPALES ==========

void inicializarLCD() {
    Serial.println("\n=== Inicializando LCD ===");
    lcd.begin();
    
    if (lcd.detectar()) {
        Serial.println("✅ LCD detectado en 0x27");
    } else {
        Serial.println("⚠️ LCD no detectado - Verificar conexiones");
    }
    
    lcd.mostrarInicio();
    delay(2000);
}

void inicializarSensores() {
    Serial.println("\n=== Inicializando Sensores ===");
    
    sensorCapacitivo.begin();
    sensorCapacitivo.calibrar(3430, 290, 3130, 3140);
    sensorCapacitivo.setNumLecturas(50);
    Serial.println("✅ Sensor capacitivo OK");
    
    sensorTurbidez1.begin();
    sensorTurbidez1.calibrar(243, 205);
    Serial.println("✅ Sensor turbidez 1 OK");
    
    sensorTurbidez2.begin();
    sensorTurbidez2.calibrar(243, 205);
    Serial.println("✅ Sensor turbidez 2 OK");
}

void leerSensores() {
    lcd.mostrarLeyendoSensores();
    
    Serial.println("\n╔════════════════════════════════════════════╗");
    Serial.println("║         LEYENDO SENSORES SAFEFRY          ║");
    Serial.println("╚════════════════════════════════════════════╝");
    
    // ===== SENSOR CAPACITIVO =====
    Serial.println("\n📊 SENSOR CAPACITIVO:");
    datos.capacitivoRaw = sensorCapacitivo.leerRaw();
    datos.capacitivoPorcentaje = sensorCapacitivo.leerPorcentaje();
    datos.capacitivoEstado = sensorCapacitivo.obtenerEstadoDetallado(datos.capacitivoPorcentaje);
    datos.capacitivoApto = (datos.capacitivoPorcentaje < UMBRAL_CAPACITIVO);
    
    Serial.print("  RAW: ");
    Serial.print(datos.capacitivoRaw);
    Serial.print(" | Degradación: ");
    Serial.print(datos.capacitivoPorcentaje, 1);
    Serial.print("% | Estado: ");
    Serial.print(datos.capacitivoEstado);
    Serial.print(" | ");
    Serial.println(datos.capacitivoApto ? "✅ APTO" : "❌ NO APTO");
    
    // ===== SENSORES DE TURBIDEZ =====
    Serial.println("\n🌊 SENSORES DE TURBIDEZ:");
    datos.turbidez1Raw = sensorTurbidez1.leerRaw();
    float turbidez1Porcentaje = (datos.turbidez1Raw >= 0) ? sensorTurbidez1.leerPorcentajeSuciedad() : -1;
    
    datos.turbidez2Raw = sensorTurbidez2.leerRaw();
    float turbidez2Porcentaje = (datos.turbidez2Raw >= 0) ? sensorTurbidez2.leerPorcentajeSuciedad() : -1;
    
    if (turbidez1Porcentaje >= 0 && turbidez2Porcentaje >= 0) {
        datos.turbidezPromedio = (turbidez1Porcentaje + turbidez2Porcentaje) / 2.0;
        Serial.print("  Sensor 1: ");
        Serial.print(datos.turbidez1Raw);
        Serial.print(" (");
        Serial.print(turbidez1Porcentaje, 1);
        Serial.println("%)");
        Serial.print("  Sensor 2: ");
        Serial.print(datos.turbidez2Raw);
        Serial.print(" (");
        Serial.print(turbidez2Porcentaje, 1);
        Serial.println("%)");
    } else if (turbidez1Porcentaje >= 0) {
        datos.turbidezPromedio = turbidez1Porcentaje;
        Serial.println("  ⚠️ Solo Sensor 1 funcionando");
    } else if (turbidez2Porcentaje >= 0) {
        datos.turbidezPromedio = turbidez2Porcentaje;
        Serial.println("  ⚠️ Solo Sensor 2 funcionando");
    } else {
        Serial.println("  ❌ Error: Ningún sensor responde");
        datos.turbidezPromedio = -1;
        datos.turbidezApto = false;
    }
    
    if (datos.turbidezPromedio >= 0) {
        datos.turbidezEstado = sensorTurbidez1.obtenerEstadoDetallado(datos.turbidezPromedio);
        datos.turbidezApto = (datos.turbidezPromedio < UMBRAL_TURBIDEZ);
        
        Serial.print("  Promedio: ");
        Serial.print(datos.turbidezPromedio, 1);
        Serial.print("% NTU | Estado: ");
        Serial.print(datos.turbidezEstado);
        Serial.print(" | ");
        Serial.println(datos.turbidezApto ? "✅ APTO" : "❌ NO APTO");
    }
    
    // ===== DECISIÓN FINAL =====
    datos.sistemaApto = datos.capacitivoApto && datos.turbidezApto;
    datos.decisionFinal = datos.sistemaApto ? "✅ APTO" : "❌ NO APTO";
    
    Serial.println("\n╔════════════════════════════════════════════╗");
    Serial.print("║        DECISIÓN FINAL: ");
    Serial.print(datos.decisionFinal);
    Serial.print(datos.sistemaApto ? "          " : "       ");
    Serial.println("║");
    Serial.println("╚════════════════════════════════════════════╝");
    
    if (!datos.sistemaApto) {
        Serial.println("\n⚠️ RAZONES:");
        if (!datos.capacitivoApto) {
            Serial.print("  • Alta degradación: ");
            Serial.print(datos.capacitivoPorcentaje, 1);
            Serial.println("%");
        }
        if (!datos.turbidezApto) {
            Serial.print("  • Alta turbidez: ");
            Serial.print(datos.turbidezPromedio, 1);
            Serial.println(" NTU");
        }
    }
    
    Serial.println();
}

// ========== SETUP ==========
void setup() {
    Serial.begin(115200);
    delay(2000);
    
    Serial.println("\n\n");
    Serial.println("╔════════════════════════════════════════════╗");
    Serial.println("║       SAFEFRY - SISTEMA DE MONITOREO      ║");
    Serial.println("║     Calidad de Aceite v2.0 WiFi + UDP     ║");
    Serial.println("╚════════════════════════════════════════════╝");
    
    // Inicializar LED WiFi
    pinMode(LED_WIFI, OUTPUT);
    digitalWrite(LED_WIFI, LOW);
    
    // Inicializar pulsador
    boton.begin();
    Serial.println("\n✅ Pulsador inicializado (GPIO 26)");
    
    // Inicializar LCD
    inicializarLCD();
    
    // Conectar WiFi
    conectarWiFi();
    
    // Inicializar sensores
    inicializarSensores();
    
    // Mostrar pantalla de espera
    lcd.mostrarEsperandoBoton();
    
    Serial.println("\n✅ Sistema listo");
    Serial.println("💡 Presiona el botón para INICIAR/PAUSAR mediciones");
    Serial.println("🌐 Dashboard disponible en: http://10.172.94.8:1880/ui\n");
}

// ========== LOOP ==========
void loop() {
    // Verificar WiFi periódicamente
    static unsigned long ultimaVerificacionWiFi = 0;
    if (millis() - ultimaVerificacionWiFi > 30000) {  // Cada 30 segundos
        verificarWiFi();
        ultimaVerificacionWiFi = millis();
    }
    
    // Procesar comandos UDP
    procesarComandosUDP();
    
    // Verificar botón físico
    if (boton.presionado()) {
        sistemaPausado = !sistemaPausado;
        
        if (sistemaPausado) {
            Serial.println("\n⏸️  ═══════════════════════════");
            Serial.println("        SISTEMA PAUSADO");
            Serial.println("   ═══════════════════════════\n");
            lcd.mostrarPausado();
        } else {
            Serial.println("\n▶️  ═══════════════════════════");
            Serial.println("        SISTEMA INICIADO");
            Serial.println("   ═══════════════════════════\n");
            lcd.mostrarIniciandoSistema();
        }
        
        delay(500);
    }
    
    // Ejecutar mediciones si está activo
    if (!sistemaPausado) {
        unsigned long tiempoActual = millis();
        
        if (tiempoActual - ultimaMedicion >= intervaloMedicion) {
            leerSensores();
            
            // Enviar datos por UDP
            enviarDatosUDP();
            
            // Calcular promedio RAW de turbidez
            int turbidezRawPromedio = (datos.turbidez1Raw + datos.turbidez2Raw) / 2;
            
            // Mostrar en LCD
            lcd.mostrarResultados(datos.capacitivoRaw, datos.capacitivoPorcentaje, 
                                 turbidezRawPromedio, datos.turbidezPromedio, 
                                 datos.sistemaApto);
            
            ultimaMedicion = tiempoActual;
        }
    } else {
        delay(50);
    }
}

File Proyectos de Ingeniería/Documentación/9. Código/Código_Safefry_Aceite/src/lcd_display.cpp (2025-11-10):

#include "lcd_display.h"

LCDDisplay::LCDDisplay(uint8_t addr, int sda, int scl) {
    direccion = addr;
    sdaPin = sda;
    sclPin = scl;
    lcd = new LiquidCrystal_I2C(direccion, 16, 2);
}

void LCDDisplay::begin() {
    Wire.begin(sdaPin, sclPin);
    lcd->init();
    lcd->backlight();
    lcd->clear();
}

bool LCDDisplay::detectar() {
    Wire.beginTransmission(direccion);
    byte error = Wire.endTransmission();
    return (error == 0);
}

void LCDDisplay::mostrarInicio() {
    lcd->clear();
    lcd->setCursor(2, 0);
    lcd->print("SAFEFRY v1.1");
    lcd->setCursor(0, 1);
    lcd->print("Monitor Aceite");
    delay(2000);
    
    lcd->clear();
    lcd->setCursor(0, 0);
    lcd->print("Inicializando");
    lcd->setCursor(0, 1);
    lcd->print("sensores...");
}

void LCDDisplay::mostrarEsperandoBoton() {
    lcd->clear();
    lcd->setCursor(1, 0);
    lcd->print("Presiona boton");
    lcd->setCursor(2, 1);
    lcd->print("para iniciar");
}

void LCDDisplay::mostrarIniciandoSistema() {
    lcd->clear();
    lcd->setCursor(2, 0);
    lcd->print("Iniciando...");
    lcd->setCursor(4, 1);
    lcd->print("Sistema");
    delay(1000);
}

void LCDDisplay::mostrarLeyendoSensores() {
    lcd->clear();
    lcd->setCursor(3, 0);
    lcd->print("Leyendo");
    lcd->setCursor(3, 1);
    lcd->print("sensores...");
}

void LCDDisplay::mostrarResultados(int capacitanciaRaw, float capacitanciaPorcentaje, 
                                    int turbidezRaw, float turbidezPorcentaje, 
                                    bool sistemaApto) {
    // ===== PANTALLA 1: Valores RAW + Porcentajes (3 segundos) =====
    lcd->clear();
    
    // Línea 1: Valores RAW
    lcd->setCursor(0, 0);
    lcd->print("C:");
    lcd->print(capacitanciaRaw);  // Valor RAW capacitancia
    
    lcd->setCursor(8, 0);
    lcd->print("T:");
    lcd->print(turbidezRaw);  // Valor RAW promedio turbidez
    
    // Línea 2: Porcentajes de degradación
    lcd->setCursor(0, 1);
    lcd->print((int)capacitanciaPorcentaje);
    lcd->print("%");
    
    lcd->setCursor(8, 1);
    lcd->print((int)turbidezPorcentaje);
    lcd->print("%");
    
    // Indicador de estado
    lcd->setCursor(14, 1);
    if (sistemaApto) {
        lcd->print("OK");
    } else {
        lcd->print("!!");
    }
    
    delay(3000);
    
    // ===== PANTALLA 2: Decisión final (2 segundos) =====
    lcd->clear();
    lcd->setCursor(0, 0);
    lcd->print("DECISION FINAL:");
    
    lcd->setCursor(2, 1);
    if (sistemaApto) {
        lcd->print("*** APTO ***");
    } else {
        lcd->print("** NO APTO **");
    }
    
    delay(2000);
}

void LCDDisplay::mostrarPausado() {
    lcd->clear();
    lcd->setCursor(3, 0);
    lcd->print("SISTEMA");
    lcd->setCursor(3, 1);
    lcd->print("PAUSADO");
}

void LCDDisplay::mostrarError(String mensaje) {
    lcd->clear();
    lcd->setCursor(0, 0);
    lcd->print("ERROR:");
    lcd->setCursor(0, 1);
    lcd->print(mensaje.substring(0, 16));
}

// ========== NUEVAS FUNCIONES PARA WiFi ==========

void LCDDisplay::mostrarConectandoWiFi() {
    lcd->clear();
    lcd->setCursor(1, 0);
    lcd->print("Conectando");
    lcd->setCursor(4, 1);
    lcd->print("WiFi...");
}

void LCDDisplay::mostrarWiFiConectado(String ip) {
    lcd->clear();
    lcd->setCursor(2, 0);
    lcd->print("WiFi OK!");
    lcd->setCursor(0, 1);
    
    // Mostrar IP completa si cabe, sino solo los últimos 16 caracteres
    if (ip.length() <= 16) {
        lcd->print(ip);
    } else {
        // Mostrar solo la parte final de la IP
        lcd->print(ip.substring(ip.length() - 16));
    }
}

// ================================================

void LCDDisplay::limpiar() {
    lcd->clear();
}

void LCDDisplay::backlight(bool encender) {
    if (encender) {
        lcd->backlight();
    } else {
        lcd->noBacklight();
    }
}

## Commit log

2025-09-16 regresion jander
    [CO_Nebraska_2022.csv, CO_Nebraska_2022_2023_daily_state_mean.csv, CO_Nebraska_2023.csv]
2025-09-17 Rename Proyectos de Ingeniería/Talleres/Modelos de Aprendizaje Supervisado/Gisela Oscco/Untitled59.ipynb to Proyectos de Ingeniería/Talleres/Modelos de Aprendizaje Supervisado/Ejemplo_de regresion_li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
2025-09-23 Update and rename Proyectos de Ingeniería/Talleres/Guía 1 - Regresión/Gisela Ossco/README.md to Proyectos de Ingeniería/Talleres/Guía 1 - Regresión/Gisela Ossco INFORME.md
2025-10-20 Enhance valuation table with image and description
    Added an image and introductory text for the evaluation of concepts in the SafeFry prototype.
2025-10-30 Include link to interactive 3D PCB model
    Added a section for interactive 3D PCB model visualization.
2025-11-04 Document 3D model of SafeFry prototype
    Added detailed documentation for the 3D model of the SafeFry prototype, including descriptions and images of the main components: carcasa, porta-muestra, tapa superior, and tapa lateral.
2025-11-04 Update description of SafeFry prototype components
2025-11-04 Update schematic figures and captions in documentation
2025-11-04 Update images in schematic documentation
2025-11-10 Add SafeFry: Sistema de monitoreo de calidad de aceite con ESP32
2025-11-10 Update print statement from 'Hello' to 'Goodbye'
2025-11-18 Rename gisela.oscco@upch.pe-Gestion-de-la-madurez-tecnologica-TRL-Technology-readiness-levels-Constancia-Niveles-de-Madurez-Tecnologica-2023-Vinculate-Cursos.pdf to Gisela Oscco.pdf
2025-11-24 Add SafeFry Pro Node-RED flow configuration
    Added a new Node-RED flow for SafeFry Pro system monitoring, including UDP input, JSON parsing, data storage, and various UI components for displaying metrics and controls.
